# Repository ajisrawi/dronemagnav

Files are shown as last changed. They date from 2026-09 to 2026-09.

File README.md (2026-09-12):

# DroneMagNav — magnetic-anomaly navigation board for drones

GNSS-denied positioning from the Earth's crustal magnetic field, plus a
phone-operated great-circle route planner.

```
  LIS3MDL magnetometer ─┐                          ┌─ WDMAM anomaly map (SD)
  BMI088 IMU ───────────┼─ ESP32-S3 ─ particle ────┤  WMM core field model
  BMP280 baro ──────────┘   filter    matching     └─ Tolles-Lawson compensation
        │                        │
   u-blox GNSS (init/truth)      ├─ MAVLink GPS_INPUT → flight controller
                                 └─ WiFi AP → phone: offline map, route, upload
```

## Deliverables

| Item | Where | Status |
|---|---|---|
| Schematics (5 sheets) | `hardware/dronemagnav/*.kicad_sch`, `dronemagnav-schematic.pdf` | ERC 0 errors (1 intended warning) |
| PCB 64 × 60 mm, 4-layer, 30.5 mm Pixhawk hole pattern | `hardware/dronemagnav/dronemagnav.kicad_pcb` | routed, 0 unconnected, 0 electrical DRC |
| Fab package | `hardware/dronemagnav/fab/` (Gerber ZIP, drill, pick-and-place) | ready to upload |
| BOM | `docs/BOM.csv` | 28 line items, 56 parts, MPNs |
| Firmware (ESP32-S3, PlatformIO) | `firmware/`, images in `firmware/release/` | compiles with 0 warnings (Arduino-ESP32 3.3.11); WMM core-field model validated 100/100 against NOAA test vectors (0.001 nT) |
| Phone UI | `firmware/sdcard/www/index.html` | offline map, tap-to-route, upload |
| SD-card preparation | `tools/prepare_sd.py` | WDMAM v2 (1.5 GB text) → 51.9 MB binary grid, verified by `tools/wdmam_check.py`; WMM, coastline |
| Design document | `DroneMagNav-Design-Document.pdf` | study, diagrams, PCB, BOM, verification |

## Hardware
| Block | Part | Why |
|---|---|---|
| MCU / radio | ESP32-S3-WROOM-1-N16R8 | WiFi AP for the phone page, BLE, native USB, 8 MB PSRAM for map tiles + particle filter |
| Magnetometer | LIS3MDL (SPI) | 16-bit, ~40 nT after averaging; RM3100 upgrade via mast connector J5 |
| IMU | BMI088 (SPI) | drone-grade accel + gyro, vibration-robust |
| Barometer | BMP280 (SPI) | altitude for the field model |
| GNSS | u-blox MAX-M10S + U.FL | initialisation and truth reference |
| Storage | microSD (SDMMC 4-bit) | world anomaly map, WMM, coastline, web page |
| Interfaces | USB-C, JST-GH TELEM (MAVLink, 5 V in), JST-GH sensor mast (I2C) | Pixhawk-standard |
| Power | USB/FC 5 V → AMS1117-3.3 (digital) + AP2112K-3.3 (sensors) | separate clean sensor rail |

## How it navigates
1. **Compensate** the scalar field for the drone's own magnetism (18-term
   Tolles-Lawson, fitted once in flight with GNSS).
2. **Predict** position with the flight controller's velocity (or IMU dead
   reckoning) in a 600-particle filter.
3. **Update** each particle against *WMM core field + WDMAM anomaly* at the
   particle's location; resample; output mean and 1-σ.
4. **Feed** the estimate to the autopilot as `GPS_INPUT` when GNSS is lost.

**Expectations, honestly:** the WDMAM world grid is 3 arc-min (~5 km) and
upward-continued to 5 km, so with it alone you get drift-free
*kilometre-class* positioning — right for oceanic/jammed cruise, not landing.
Load a local aeromagnetic survey (`/maps/local.bin`, same format) for tens of
metres at drone altitude.

## Routing
The phone page shows an offline world coastline, you tap START and DEST, the
board computes the **great-circle** (shortest) path as evenly spaced waypoints
and uploads them to the flight controller as a MAVLink mission.

## Build / flash / prepare
See `firmware/README.md`. Short version: `pio run -t upload` over USB-C, then
`python tools/prepare_sd.py --wdmam <file> --wmm WMM.COF --coast <geojson>`
and copy `firmware/sdcard/*` to the card.

## Status / caveats
- Prototype; not certified for any regulated use.
- Firmware builds cleanly (PlatformIO, pioarduino platform, Arduino-ESP32
  core 3.3.11: 0 warnings, 1.08 MB flash of 4 MB app partition, 94 KB RAM).
  Ready-to-flash images are in `firmware/release/`. It has not yet run on
  real hardware, since the board has not been built.
- Vias in pads: 74 power vias were moved out of their pads into dog-bone
  stubs. Three remain where the routing leaves no room (BMI088 pads 2 and 4,
  microSD VDD pad) and must be filled and capped, see
  `hardware/dronemagnav/fab/FABRICATION-NOTES.md` (included in the Gerber ZIP).
- MAX-M10S straps checked against the u-blox integration manual
  (UBX-20053088 R05): `VIO_SEL` left open selects 3.3 V I/O, which is what the
  board supplies, so no change was needed. TIMEPULSE is tied inside the module
  to SAFEBOOT_N, so the firmware keeps GPIO16 input-only.
- Map data: WDMAM from the link you supplied; WMM.COF (NOAA) and Natural Earth
  coastline are free downloads you run through `prepare_sd.py`.

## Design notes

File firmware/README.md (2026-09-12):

# DroneMagNav firmware (ESP32-S3)

Magnetic-anomaly navigation (MagNav) + great-circle route planner for drones.

```
firmware/
├── platformio.ini          build config (PlatformIO, Arduino-ESP32, N16R8)
├── partitions.csv          16 MB flash layout (dual OTA app slots)
├── src/
│   ├── main.cpp            sensor loop, attitude, MagNav filter, FC feed
│   ├── pins.h              board pin map (schematic rev A)
│   ├── sensors/            bmi088.h  lis3mdl.h  bmp280.h  (register-level SPI)
│   ├── nav/
│   │   ├── wmm.h           World Magnetic Model core field (coeffs from SD)
│   │   ├── wdmam_map.h     anomaly-map window cache (WDMAM / local survey)
│   │   ├── tolles_lawson.h 18-term aircraft-field compensation + fit
│   │   ├── particle_filter.h  600-particle MagNav estimator
│   │   └── geo.h           great-circle distance / bearing / waypoints
│   └── comm/
│       ├── gnss.h          u-blox NMEA parser
│       ├── mavlink_lite.h  MAVLink v2: heartbeat, GPS_INPUT, mission upload
│       └── web_ui.h        WiFi AP + HTTP API for the phone page
└── sdcard/                 staging tree for the microSD (see tools/prepare_sd.py)
    ├── www/index.html      mobile map page (offline coastline, tap-to-route)
    └── maps/               wdmam.bin, WMM.COF, coast.json  (generated)
```

## 0. Ready-made images (no toolchain needed)
`release/` holds the verified build (Arduino-ESP32 core 3.3.11, 0 warnings,
1.08 MB flash / 94 KB RAM). One command with [esptool](https://pypi.org/project/esptool/):
```bash
esptool --chip esp32s3 --port COM5 --baud 921600 write-flash 0x0 release/dronemagnav-firmware.factory.bin
```
(`factory.bin` already contains bootloader, partition table and app.)

## 1. Install the toolchain
Install [PlatformIO Core](https://platformio.org/install/cli) (or the VS Code
extension), e.g. `pip install platformio`. `platformio.ini` points at the
pioarduino build of the Espressif platform, so the toolchain and Arduino-ESP32
core are fetched from GitHub on the first build (~1.5 GB, one time).

## 2. Build
```bash
cd firmware
pio run
```
Verified result: `[SUCCESS]`, RAM 29.3 % (95,876 B), Flash 25.7 % (1,077,723 B
of the 4 MB app partition), no compiler warnings.

## 3. Flash (USB-C, no external programmer)
```bash
pio run -t upload
```
First time only: hold **BOOT**, tap **RESET**, release BOOT — the ESP32-S3
enters its ROM bootloader on the native USB port. Afterwards the USB-CDC
auto-reset handles it. `pio device monitor -b 115200` shows the boot log.

## 4. Prepare the microSD card
```bash
python tools/prepare_sd.py --wdmam data/<WDMAM file> --wmm WMM.COF --coast ne_110m_coastline.geojson
```
then copy `firmware/sdcard/*` to the card root (FAT32, ≤ 32 GB recommended).

| File | Source |
|---|---|
| `maps/wdmam.bin` | converted from the WDMAM v2 text grid you supplied (1.5 GB xyz, 26 M lines → 7200 × 3601 int16 cells, 51.9 MB; ~2 min) |
| `maps/WMM.COF` | NOAA/NCEI World Magnetic Model coefficients (free) |
| `maps/coast.json` | Natural Earth 1:110m coastline GeoJSON (public domain) |
| `maps/local.bin` | optional: your own high-resolution aeromagnetic survey, same format |

## 5. Use it
1. Power from USB-C or the flight controller TELEM port. Join WiFi
   **DroneMagNav** / `magnav123`, open **http://192.168.4.1/** on your phone.
2. **Calibrate once** (Tolles-Lawson): with GNSS fix, tap *Start calibration*,
   fly pitch/roll/yaw manoeuvres on four headings for ~3 min, tap *Stop*.
   Coefficients are saved to `/cal/tl.bin`.
3. **Route:** tap *Set START = here* (or tap the map), tap the destination,
   *Compute route* → great-circle waypoints → *Upload to flight controller*.
4. **MagNav:** when GNSS is lost the filter takes over automatically (or tap
   *Init* to force it) and streams its fix to the FC as `GPS_INPUT`
   (ArduPilot: set `GPS_TYPE=14`, or `GPS_TYPE2=14` for blended use).

## Honest performance expectations
The WDMAM world grid is 3 arc-minutes (~5 km) and is upward-continued to
5 km altitude — it only contains long-wavelength anomalies. With it alone the
filter gives **kilometre-class** positioning, drift-free: good for oceanic /
GNSS-jammed cruise, not for precision landing. For tens-of-metres accuracy at
drone altitude load a local aeromagnetic survey as `/maps/local.bin`. The
LIS3MDL is adequate for the world grid; an RM3100 on the mast connector (J5)
is the upgrade for local-survey navigation.

Not compile-verified on hardware yet — see the project README for status.

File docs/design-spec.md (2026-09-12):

# DroneMagNav — Design Specification (rev A)

## 1. Purpose
A drone-mountable navigation module that estimates position without GNSS by
matching the measured total magnetic field against the World Digital Magnetic
Anomaly Map (WDMAM), fused with inertial dead reckoning; and a phone interface
to plan and upload direct (great-circle) routes.

## 2. Architecture
| Function | Implementation |
|---|---|
| Compute + radio | ESP32-S3-WROOM-1-N16R8: dual-core 240 MHz, 8 MB PSRAM, WiFi/BLE, USB-CDC |
| Sensing | LIS3MDL mag, BMI088 IMU, BMP280 baro — one SPI bus at 8–10 MHz |
| Reference | u-blox MAX-M10S GNSS on UART0 pads (GPIO43/44), PPS on GPIO16 |
| Map storage | microSD, SDMMC 4-bit (GPIO38–42, 47), card detect GPIO48 |
| Flight controller | UART2 (GPIO4/5) MAVLink v2, Pixhawk TELEM pinout on JST-GH J2 |
| External sensor | I2C1 (GPIO1/2) + interrupt GPIO3 on JST-GH J5 (mast-mounted RM3100) |
| Power | USB-C VBUS ⊕ FC 5 V (SS14 diode-OR) → AMS1117-3.3 → +3V3; AP2112K-3.3 → +3.3VA |

## 3. Pin map
| ESP32-S3 | Net | | ESP32-S3 | Net |
|---|---|---|---|---|
| IO12 | SPI_SCK | | IO38/39/40/41/42/47 | SD_CLK/CMD/D0/D1/D2/D3 |
| IO11 | SPI_MOSI | | IO48 | SD_DET |
| IO13 | SPI_MISO | | TXD0 (43) / RXD0 (44) | GNSS RXD / TXD |
| IO10 / IO9 | CS_ACC / CS_GYR | | IO16 | GNSS_PPS |
| IO14 / IO21 | CS_MAG / CS_BARO | | IO4 / IO5 | FC_RXD / FC_TXD |
| IO6 / IO7 / IO8 | INT_ACC / INT_GYR / MAG_DRDY | | IO1 / IO2 / IO3 | I2C_SDA / I2C_SCL / MAST_INT |
| IO35 / IO36 / IO37 | LED_NAV / LED_FIX / LED_LINK | | EN / IO0 | RESET / BOOT buttons |

## 4. Connectors
- **J1 USB-C** — power (VBUS) + native USB (D+/D− through USBLC6-2SC6 ESD).
- **J2 FC_TELEM (JST-GH 6)** — 1 VCC 5 V in, 2 FC TX → board, 3 board TX → FC, 4/5 NC, 6 GND.
- **J3 microSD** — Hirose DM3AT push-push.
- **J4 GNSS antenna** — U.FL, passive antenna, 50 Ω trace.
- **J5 SENSOR_MAST (JST-GH 6)** — 1 +3.3VA, 2 GND, 3 SDA, 4 SCL, 5 INT, 6 +5 V.

## 5. PCB
64 × 60 mm, 4 layers (F.Cu signals / In1 GND / In2 +3V3 / B.Cu signals),
30.5 mm M3 mounting pattern. ESP32 antenna at the top edge with a full copper
keep-out (module courtyard respected). USB-C left edge, microSD right edge,
GNSS + U.FL top-right, sensors centre, magnetometer bottom-centre away from
the regulators (bottom-left). Rules: 0.2 mm track, 0.15 mm clearance,
0.45/0.2 mm vias. Power vias are dog-boned outside their pads
(`tools/dogbone_vias.py`); three 0.4 mm vias stay inside pads where the
routing leaves no room (BMI088 pads 2/4, microSD VDD pad 4) and the
fabrication notes (`hardware/dronemagnav/fab/FABRICATION-NOTES.md`) require
those to be filled and capped.

## 6. Firmware
See `firmware/README.md` for the module map. Key algorithms:
- **WMM** degree-12 spherical-harmonic core field, coefficients from `WMM.COF`.
- **AnomalyMap** 96 × 96-cell PSRAM window over the int16 nT grid on SD; bilinear lookup.
- **TollesLawson** 18-term compensation; ridge-regularised least squares fit from a calibration flight.
- **MagNavPF** 600 particles (lat, lon, bias); systematic resampling at ESS < N/2, roughening.
- **MavlinkLite** HEARTBEAT, GPS_INPUT, MISSION_COUNT/ITEM_INT upload; parses GLOBAL_POSITION_INT / VFR_HUD.
- **WebUI** AP `DroneMagNav`, HTTP API: `/api/status`, `/api/route`, `/api/upload`, `/api/coast`, `/api/anom`, `/api/cal`, `/api/init`.

## 7. Map data pipeline
`tools/prepare_sd.py` converts the WDMAM grid (xyz/NetCDF/GeoTIFF) to
`/maps/wdmam.bin` (32-byte header + int16 nT, 3′ world grid ≈ 52 MB), and
stages `WMM.COF`, `coast.json` (Natural Earth 1:110m) and the web page.

The supplied WDMAM file is the v2 text distribution: 1.5 GB, 26 M lines of
`lon lat anomaly_nT source ...`, columns −179.95…180.00° and rows
90…−90° at 0.05°. The converter reads it in 2 M-line chunks, moves the
180.00° column to the front so the grid starts at exactly −180° (the
firmware wraps longitude modulo the grid width), and writes 7200 × 3601
cells. `tools/wdmam_check.py` re-reads sample lines from the source and
confirms the binary holds the same values at the cells the firmware addresses.

## 8. Verification
| Check | Result |
|---|---|
| Schematic ERC | 0 errors, 1 warning (BMI088 SDO1/SDO2 both on MISO — per Bosch reference design) |
| Netlist, 21 critical nets | 21/21 |
| PCB connectivity | 0 unconnected |
| PCB electrical DRC | 0 violations (22 silkscreen notes) |
| WMM evaluator vs NOAA WMM2025 test values | 100/100 points, worst error 0.001 nT (tools/wmm_check.py) |
| WDMAM SD grid vs source text file | 7200 × 3601 cells, 100 % valid, 225 sample cells identical (tools/wdmam_check.py) |
| MAX-M10S straps vs u-blox integration manual UBX-20053088 R05 | VIO_SEL open = 3.3 V I/O as built; V_BCKP on +3V3 within 1.5–3.6 V; RESET_N pull-up acceptable; TIMEPULSE–SAFEBOOT_N tie → GPIO16 input-only |
| Vias in pads after dog-bone pass (tools/fab_audit.py) | 74 moved out; 3 remain in small pads (fill & cap), 2 in thermal pads; DRC 0 unconnected, 0 electrical |
| Firmware build (PlatformIO, pioarduino espressif32 55.3.311, Arduino-ESP32 3.3.11) | SUCCESS, 0 warnings; flash 1,077,723 B (25.7 % of app partition), RAM 95,876 B (29.3 %) |

## 9. Known limitations
- WDMAM resolution/altitude → km-class accuracy without a local survey.
- LIS3MDL noise adequate for the world grid only; RM3100 recommended for local surveys.
- Magnetic interference from ESCs/motors must be handled by mounting distance and the Tolles-Lawson calibration.
- Firmware compiles (0 warnings) but has not yet run on hardware; the
  calibration flight and MagNav-vs-GNSS benchmark remain to be done.
- V_BCKP is tied to +3V3 (in range, but no hot start after a power cycle);
  fit a backup cell on V_BCKP if that matters.

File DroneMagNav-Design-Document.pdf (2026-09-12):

DESIGN DOCUMENT · REV A

# DroneMagNav

## Magnetic-anomaly navigation board and route planner for drones

ESP32-S3 · BMI088 IMU · LIS3MDL magnetometer · BMP280 · u-blox MAX-M10S WDMAM world anomaly map on microSD · particle-filter MagNav · MAVLink to the autopilot Phone web app: offline world map, tap start/destination, great-circle route upload

Project | DroneMagNav (GNSS-denied drone navigation)
Revision | A - schematic + routed PCB + firmware release
Date | 12 September 2026
Prepared by | eng.ahmad@gmail.com · generated with KiCad 10
Design status | ERC clean · netlist verified · PCB routed, 0 electrical DRC
Classification | Prototype / experimental - not certified

Appendix A contains the full KiCad schematic set (5 sheets, A3).

DroneMagNav - Design Document | Rev A · 12 Sep 2026

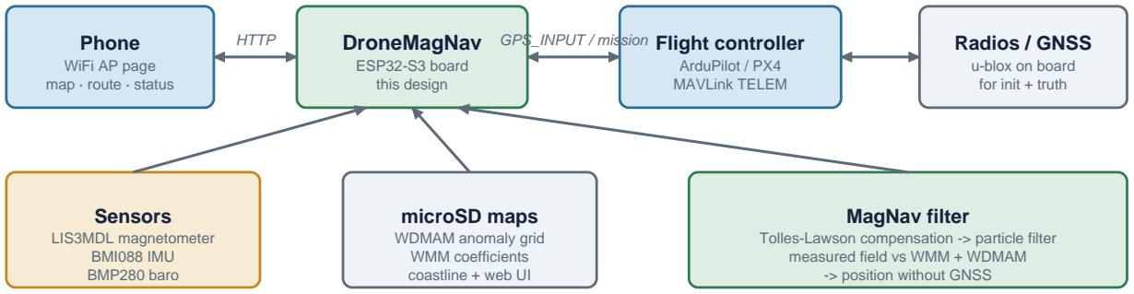
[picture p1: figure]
Phone WiFi AP page map · route · status; DroneMagNav; ESP32-S3 board this design; Flight controller ArduPilot / PX4 MAVLink TELEM; Radios / GNSS u-blox on board for init + truth; HTTP; GPS_INPUT / mission; Sensors LIS3MDL magnetometer BMI088 IMU BMP280 baro; microSD maps WDMAM anomaly grid WMM coefficients coastline + web UI; MagNav filter Tolles-Lawson compensation -> particle filter measured field vs WMM + WDMAM -> position without GNSS

Prototype - not certified for any regulated use | Page 2

# 1 Executive summary

DroneMagNav is a 64 x 60 mm navigation module for drones that estimates position without GNSS by matching the measured total magnetic field against the World Digital Magnetic Anomaly Map (WDMAM), fused with inertial dead reckoning in a particle filter. A u-blox GNSS receiver on the board initialises the filter and provides a truth reference; when GNSS is lost the MagNav estimate is streamed to the flight controller as a MAVLink GPS_INPUT source. A phone connects to the board's WiFi access point, shows an offline world map, and lets the operator tap a start and a destination; the board computes the shortest (great-circle) route and uploads it to the autopilot as a mission.
This release contains the complete KiCad schematic set, a routed four-layer PCB with manufacturing outputs, a bill of materials with part numbers, the ESP32-S3 firmware with the navigation algorithms and web interface, and the tools that convert the WDMAM data for the microSD card.

# 2 System architecture

Signal path: sensors -> compensation -> particle filter against the magnetic map -> position -> autopilot; route planned on the phone.

Figure 1 - System context

The Earth's crustal magnetic anomalies form a fixed, GNSS-independent map. Subtracting the smooth core field (World Magnetic Model) from the compensated scalar measurement leaves the anomaly, which the particle filter compares with the WDMAM grid at every particle's position. The filter is drift-free but its resolution is bounded by the map: the 3-arc-minute WDMAM grid (upward-continued to 5 km) gives kilometre-class positioning; a local aeromagnetic survey loaded in the same format brings that to tens of metres at drone altitude.

# 3 Hardware design

DroneMagNav PCB 64 x 60 mm, 4 layers

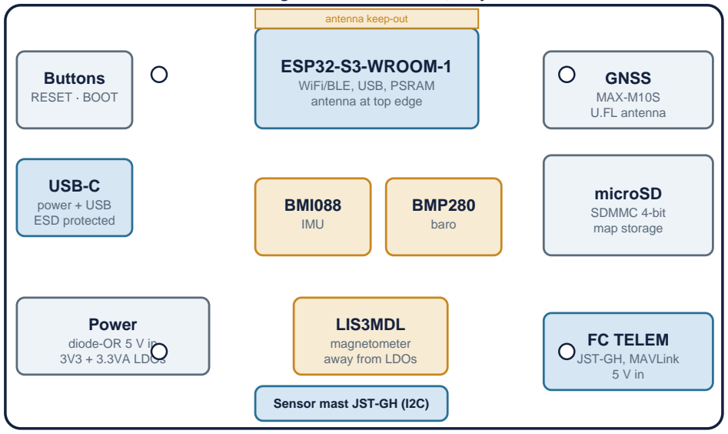
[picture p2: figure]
ESP32-S3-WROOM-1; WiFi/BLE, USB, PSRAM antenna at top edge; antenna keep-out; Buttons RESET · BOOT; USB-C power + USB ESD protected; GNSS MAX-M10S U.FL antenna; microSD SDMMC 4-bit map storage; BMI088 IMU; BMP280 baro; LIS3MDL magnetometer away from LDOs; Power diode-OR 5 V in 3V3 + 3.3VA LDOs; FC TELEM JST-GH, MAVLink 5 V in; Sensor mast JST-GH (I2C)

M3 holes on the 30.5 mm Pixhawk pattern
Figure 2 - Board floorplan
Block | Part | Notes
MCU / radio | ESP32-S3-WROOM-1-N16R8 | 16 MB flash, 8 MB PSRAM, WiFi/BLE, native USB; UART0 pads carry the GNSS
Magnetometer | LIS3MDL | 16-bit, +-4 gauss, ~40 nT after averaging; SPI
IMU | BMI088 | accel + gyro, drone grade; SPI, dual chip-select
Barometer | BMP280 | altitude input to the field model; SPI
GNSS | u-blox MAX-M10S + U.FL | init and truth; PPS to GPIO16
Storage | microSD (Hirose DM3AT) | SDMMC 4-bit, card detect
Interfaces | USB-C, JST-GH TELEM, JST-GH mast | USBLC6 ESD; Pixhawk TELEM pinout; I2C mast for RM3100
Power | SS14 diode-OR, AMS1117-3.3, AP2112K-3.3 | digital 3V3 and low-noise 3.3VA sensor rail

### 3.1 Magnetic cleanliness

The magnetometer sits at the bottom centre, 14 mm from the regulators and away from the USB and SD connectors; the ESP32 antenna keep-out is respected in full. The dominant interference on a drone is the motors and ESC currents, which no board layout can remove: the firmware's Tolles-Lawson calibration models it, and the sensor-mast connector J5 allows an external RM3100 on a boom for survey-grade use.

# 4 Navigation algorithms

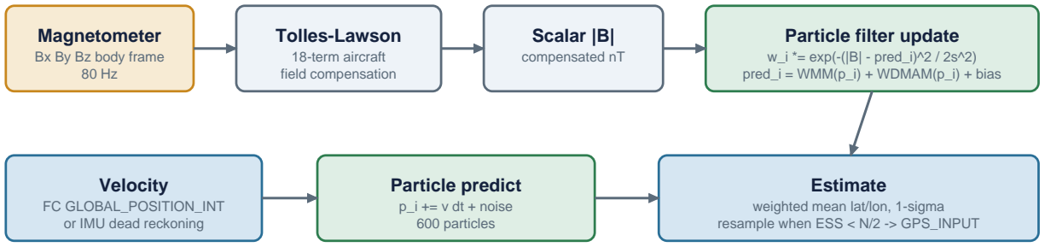
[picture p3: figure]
Magnetometer Bx By Bz body frame 80 Hz; Tolles-Lawson 18-term aircraft field compensation; Scalar |B| compensated nT; Particle filter update w_i *= exp(-(|B| - pred_i)^2 / 2s^2) pred_i = WMM(p_i) + WDMAM(p_i) + bias; Velocity FC GLOBAL_POSITION_INT or IMU dead reckoning; Particle predict p_i += v dt + noise 600 particles; Estimate weighted mean lat/lon, 1-sigma resample when ESS < N/2 -> GPS_INPUT

Figure 3 - MagNav particle filter dataflow

- WMM core field: degree-12 spherical-harmonic model evaluated per particle; coefficients read from the NOAA WMM.COF file on the card.
- WDMAM map window: 96 x 96 cells of the int16 nT world grid cached in PSRAM around the estimate, bilinear interpolation, seamless longitude wrap.
- Tolles-Lawson: 18 terms (permanent, induced, eddy) fitted by ridge-regularised least squares from a 3-minute calibration manoeuvre with GNSS; stored on the card.
- Particle filter: 600 particles (lat, lon, scalar bias); velocity from the flight controller or IMU; Gaussian likelihood with 40 nT sigma; systematic resampling with roughening.
- Routing: haversine distance, initial bearing, great-circle intermediate points at the chosen spacing; uploaded as NAV_TAKEOFF + NAV_WAYPOINT items.

# 5 PCB implementation

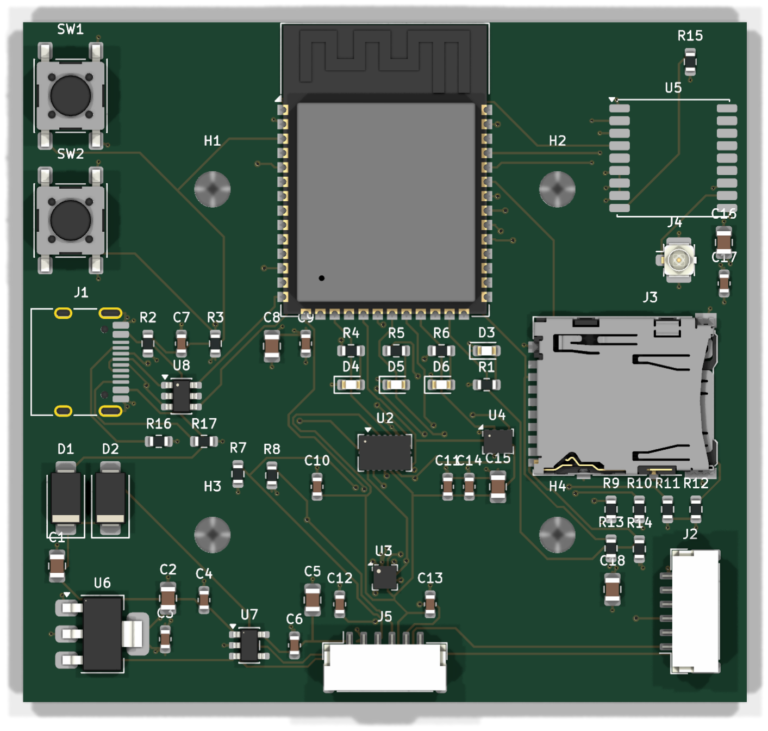
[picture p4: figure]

Figure 4 - Routed board, top side

Four layers: signals on the outer layers, solid GND (In1) and +3V3 (In2) planes inside, both notched under the module antenna. Autorouted with Freerouting constrained to the outer layers and the keep-outs, then scripted power fanout to the planes and hand-verified routes for the GNSS UART and the I2C bus. Rules: 0.2 mm track, 0.15 mm clearance, 0.45/0.2 mm vias. Power vias are dog-boned outside their pads (74 moved by tools/dogbone_vias.py); only three 0.4 mm vias remain in pads where the 0.5 mm-pitch BMI088 escapes and the microSD routing leave no room (U2 pads 2/4, J3 pad 4) and the fabrication notes require them to be filled and capped. Fab outputs: Gerbers, Excellon drill + map, pick-and-place, FABRICATION-NOTES.md, Gerber ZIP.

# 6 Bill of materials

References | Qty | Value | Manufacturer P/N
C1, C2, C5, C8, C15, C16, C18 | 7 | 10uF | CL21 series
C3, C6, C9, C10, C11, C12, ... | 9 | 100nF | CL10 series
C4, C7 | 2 | 1uF | CL10 series
D1, D2 | 2 | SS14 | SS14
D3 | 1 | PWR | 19-217/GHC-YR1S2/3T
D4 | 1 | NAV | 19-217/GHC-YR1S2/3T
D5 | 1 | FIX | 19-217/BHC-ZL1M2RY/3T
D6 | 1 | LINK | 19-217/Y2C-CQ2R2L/3T
J1 | 1 | USB-C | TYPE-C-31-M-12

References | Qty | Value | Manufacturer P/N
J2 | 1 | FC_TELEM | SM06B-GHS-TB
J3 | 1 | microSD | DM3AT-SF-PEJM5
J4 | 1 | GNSS_ANT | U.FL-R-SMT-1(10)
J5 | 1 | SENSOR_MAST | SM06B-GHS-TB
R1 | 1 | 1K | RC0603FR-071KL
R2, R3, R9, R10, R11, R12, ... | 9 | 10K | RC0603FR-0710KL
R4, R5, R6 | 3 | 330R | RC0603FR-07330RL
R7, R8 | 2 | 4.7K | RC0603FR-074.7KL
R16, R17 | 2 | 5.1K | RC0603FR-075.1KL
SW1 | 1 | RESET | PTS645SM43SMTR92
SW2 | 1 | BOOT | PTS645SM43SMTR92
U1 | 1 | ESP32-S3-WROOM -1-N16R8 | ESP32-S3-WROOM-1-N16R8
U2 | 1 | BMI088 | BMI088
U3 | 1 | LIS3MDL | LIS3MDLTR
U4 | 1 | BMP280 | BMP280
U5 | 1 | MAX-M10S | MAX-M10S-00B
U6 | 1 | AMS1117-3.3 | AMS1117-3.3
U7 | 1 | AP2112K-3.3 | AP2112K-3.3TRG1
U8 | 1 | USBLC6-2SC6 | USBLC6-2SC6

# 7 Firmware and phone interface

PlatformIO / Arduino-ESP32 project (firmware/): register-level SPI drivers for the three sensors, NMEA parser for the GNSS, a minimal MAVLink v2 stack (heartbeat, GPS_INPUT, mission upload, position/velocity intake), the navigation modules above, and a WiFi access point serving the phone page from the card. Flashing is over USB-C (native USB bootloader, no programmer). The phone page draws the Natural Earth coastline offline, pans/zooms by touch, places START/DEST by tap, shows the great-circle line, distance and bearing, and uploads the mission.

HTTP endpoint | Purpose
GET /api/status | mode, position, sigma, field, anomaly, heading, link states
GET /api/route?lat1&lon1;&lat2;&lon2;&alt;&s pacing; | great-circle waypoints, distance, bearing
POST /api/upload | send the last route to the flight controller as a mission
GET /api/anom?lat&lon;&span;&n; | anomaly grid for the heat overlay
POST /api/cal?start=1|0 | Tolles-Lawson calibration start/stop
POST /api/init?lat&lon; | force MagNav mode from a known position

# 8 Verification

Check | Tool | Result
Electrical rule check (5 sheets) | kicad-cli sch erc | 0 errors, 1 warning (BMI088 SDO1/SDO2 on MISO, per Bosch)
Netlist connectivity, 21 critical nets | tools/check_netlist.py | 21 / 21 pass
PCB connectivity | kicad-cli pcb drc | 0 unconnected pads
PCB electrical rules | kicad-cli pcb drc | 0 violations (22 silkscreen notes)
WMM core-field evaluator vs NOAA WMM2025 test values | tools/wmm_check.py | 100 / 100 points, worst error 0.001 nT
WDMAM SD-card grid vs source file (7200 x 3601 cells, 51.9 MB) | tools/wdmam_check.py | 225 sample cells identical, 100 % coverage
MAX-M10S straps vs u-blox integration manual UBX-20053088 R05 | manual, table 1 / sec. 4.1 | VIO_SEL open = 3.3 V I/O (as built); TIMEPULSE-SAFEBOOT_N tie honoured in firmware
Vias in pads after dog-bone pass | tools/fab_audit.py | 3 in small pads (listed for fill & cap), 2 in thermal pads, 0 unconnected, 0 DRC
Firmware build (PlatformIO, Arduino-ESP32 3.3.11) | pio run | SUCCESS, 0 warnings; flash 1.08 MB (25.7 %), RAM 94 KB (29.3 %); images in firmware/release

# 9 Limitations and next steps

- WDMAM resolution and 5 km altitude limit stand-alone accuracy to kilometre class; add a local survey map for metres.
- LIS3MDL is adequate for the world grid; use an RM3100 on the mast connector for survey-grade work.
- Order the board with filled-and-capped vias (three vias-in-pad, see FABRICATION-NOTES.md in the Gerber ZIP).

- Flash firmware/release/dronemagnav-firmware.factory.bin, run the calibration flight, benchmark MagNav against GNSS before relying on it.

# Appendix A - Schematic sheets

Root, power, MCU, sensors, GNSS + storage, interfaces - as plotted from KiCad. Every pin carries a drawn wire stub with its net label; the netlist is the authoritative artifact validated in Section 8.

1 | 2 | 3 | 4 | 5 | 6 | 7 | 8

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
F Date:
KiCad E.D.A. 10.0.3
Size: A3 | Rev: A Id: 1/6

Title: DroneMagNav - magnetic anomaly navigation board for drones

File: dronemagnav.kicad_sch

Sheet: /

DroneMagNav Project

ESP32-S3 + BMI088 + LIS3MDL + BMP280 + MAX-M10S + microSD

MCU

File: mcu.kicad_sch | Sensors File: sensors.kicad_sch | GNSS (u-blox MAX-M10S) and microSD map storage

File: gnss_storage.kicad_sch

Interfaces File: interfaces.kicad_sch Power File: power.kicad_sch

MagNav: measure Earth's crustal magnetic anomaly with the magnetometer, subtract the core field (WMM), match against the WDMAM map on the SD card

with a particle filter fused with IMU dead-reckoning -> GNSS-denied position. GNSS module gives initialisation and truth for testing.

Phone UI over WiFi AP: pick start/destination on the offline map, great-circle route + waypoints sent to the flight controller (MAVLink).

Prototype hardware - not certified for any regulated use.

### 10uF +5V GND

### SS14 D1

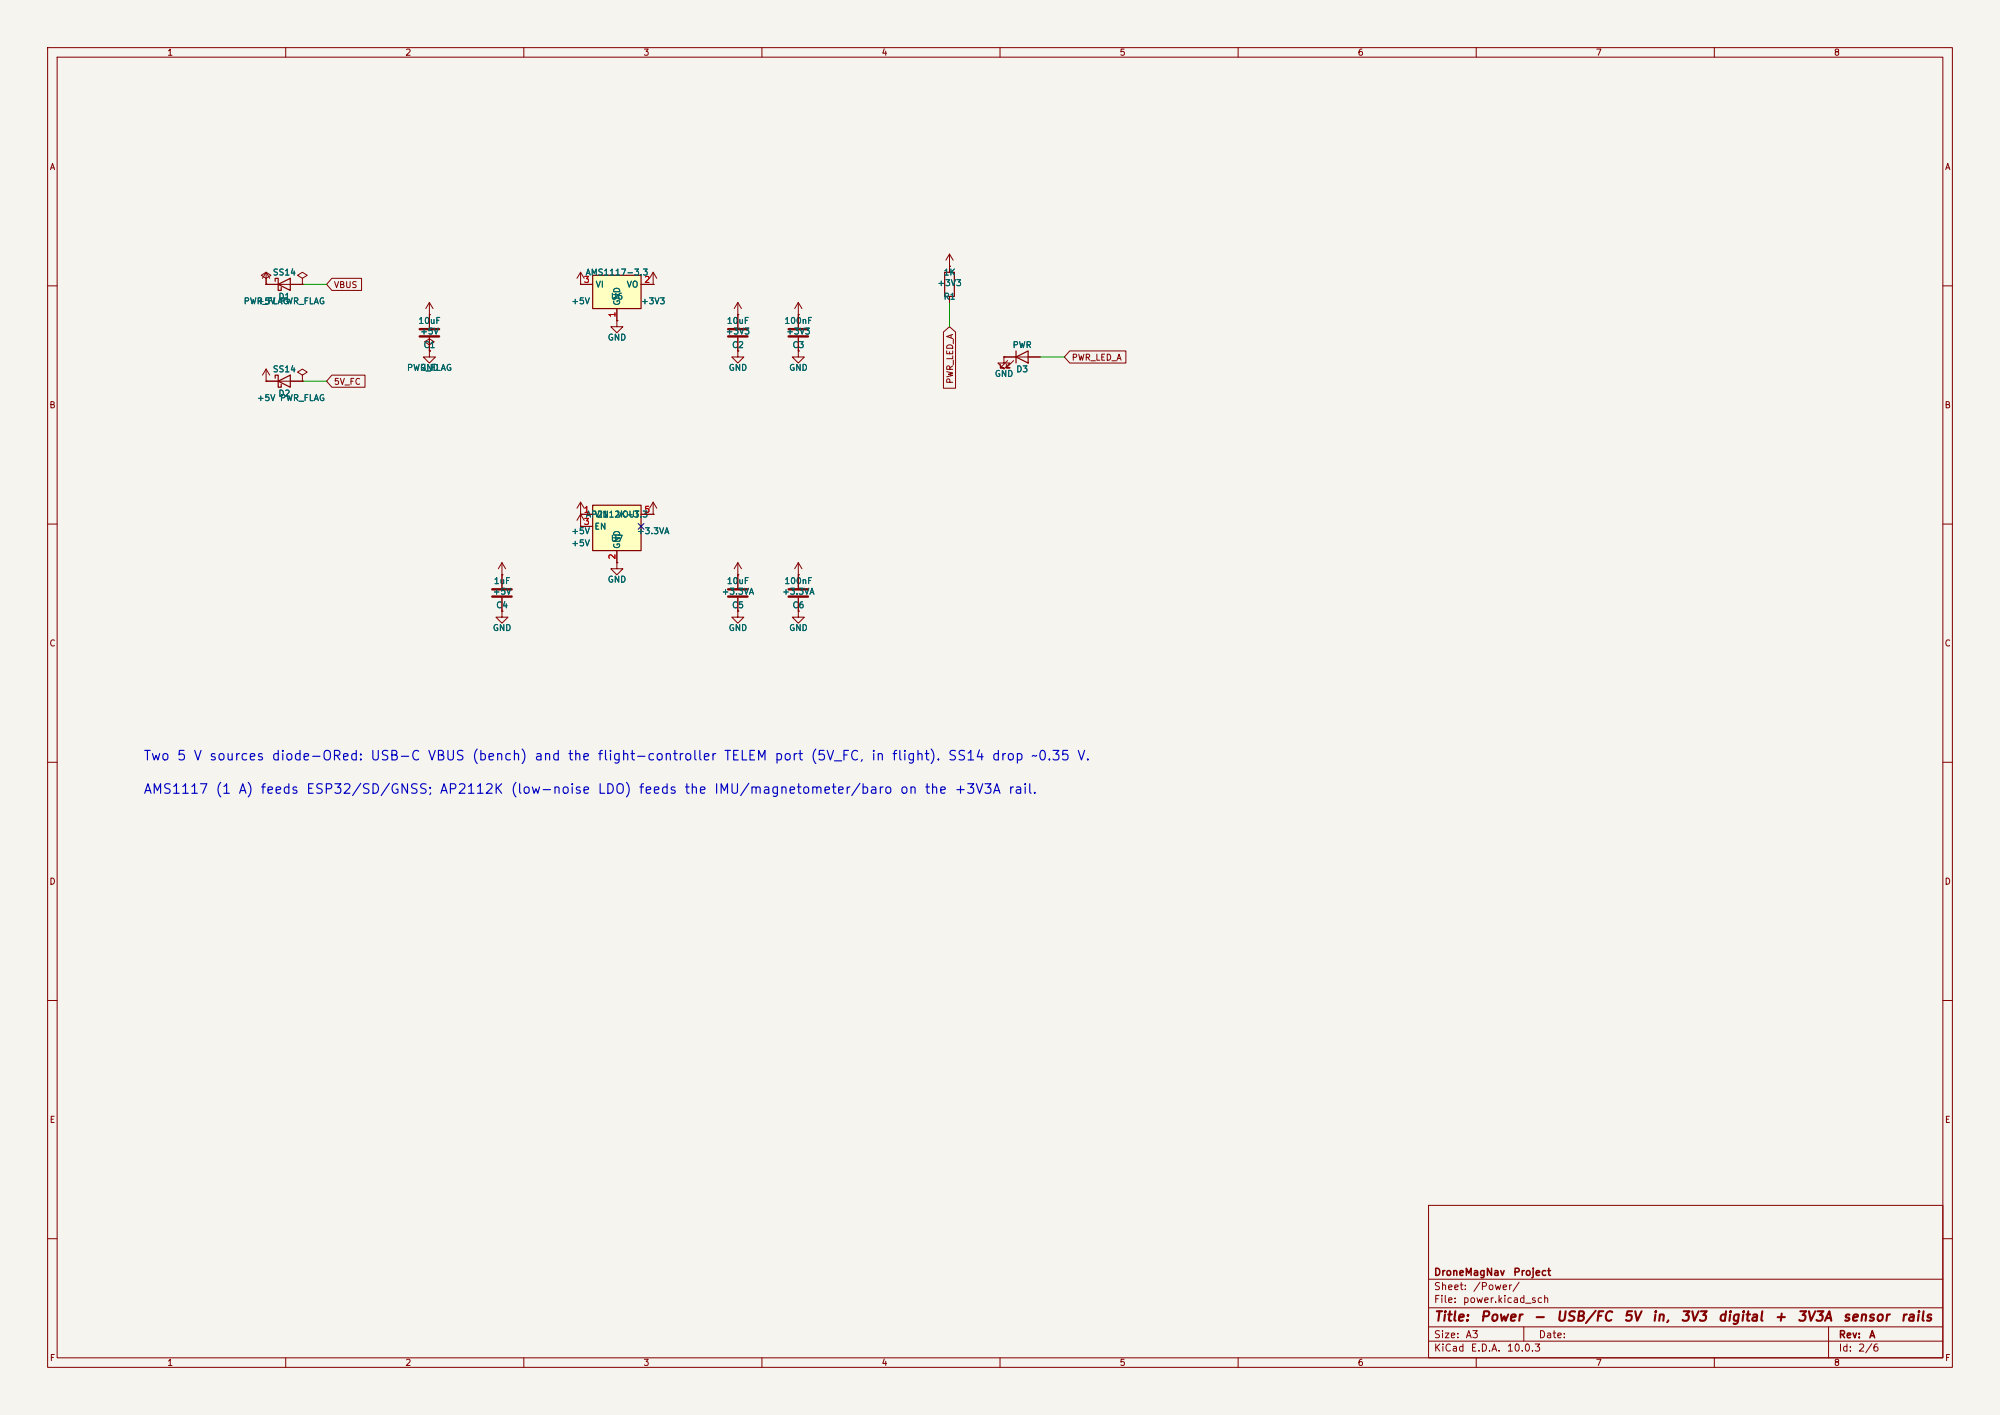
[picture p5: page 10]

VBUS AMS1117 (1 A) feeds ESP32/SD/GNSS; AP2112K (low-noise LDO) feeds the IMU/magnetometer/baro on the +3V3A rail.

Two 5 V sources diode-ORed: USB-C VBUS (bench) and the flight-controller TELEM port (5V_FC, in flight). SS14 drop ~0.35 V.

DroneMagNav Project
Sheet: /Power/
File: power.kicad_sch
Title: Power - USB/FC 5V in, 3V3 digital + 3V3A sensor rails

# 100nF +3V3 GND

# GND SW1 RESET R2

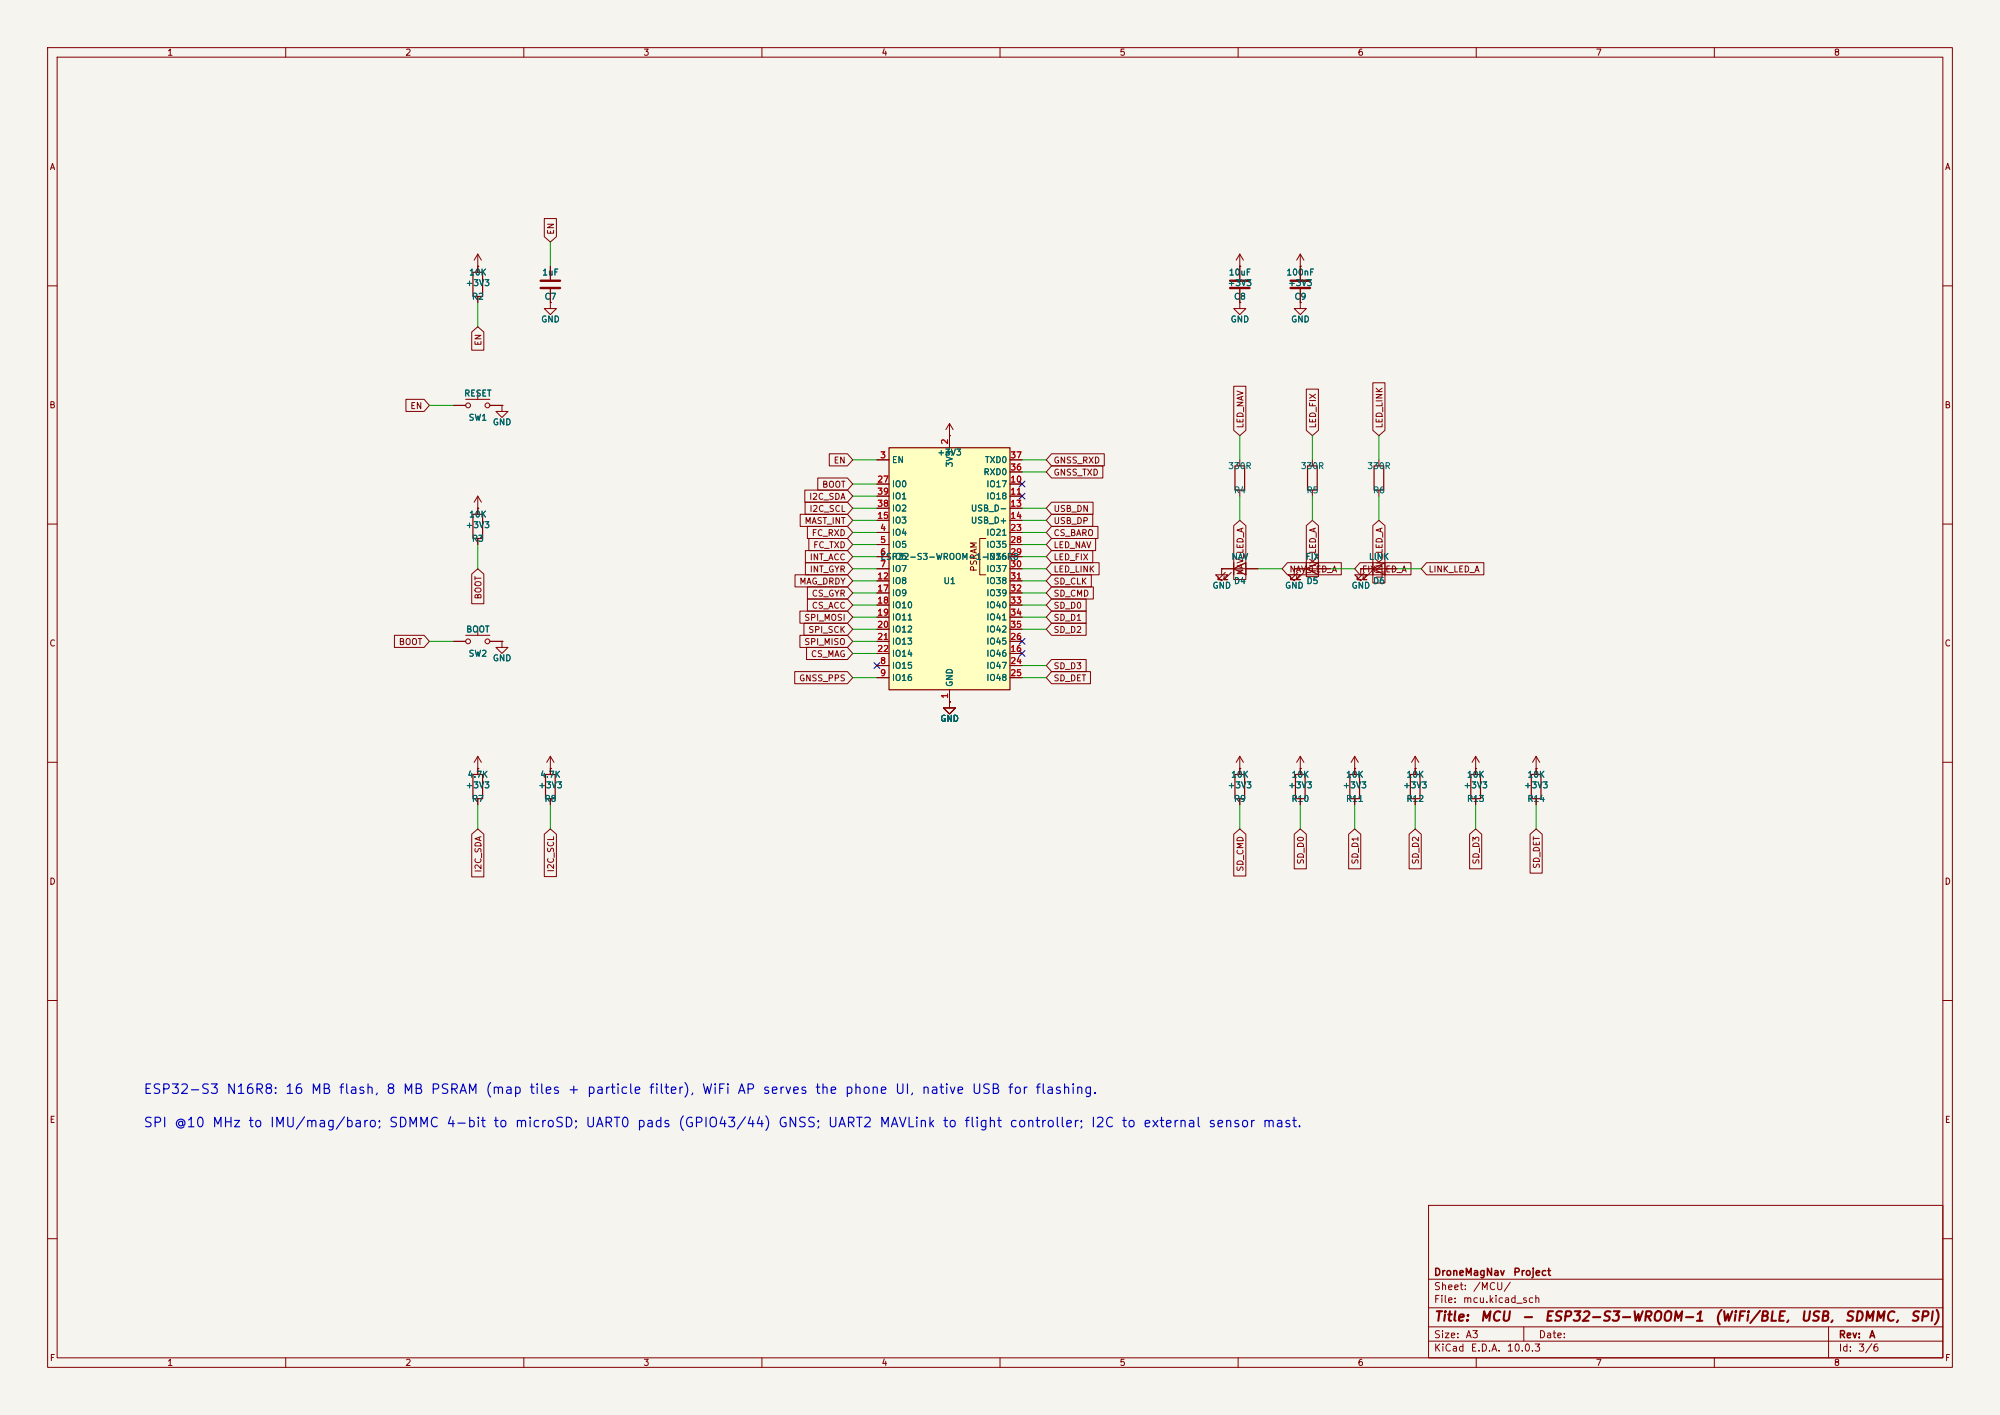
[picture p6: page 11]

DroneMagNav Project PSRAM GND

ESP32-S3 N16R8: 16 MB flash, 8 MB PSRAM (map tiles + particle filter), WiFi AP serves the phone UI, native USB for flashing.

Sheet: /MCU/
File: mcu.kicad_sch
Title: MCU - ESP32-S3-WROOM-1 (WiFi/BLE, USB, SDMMC, SPI)

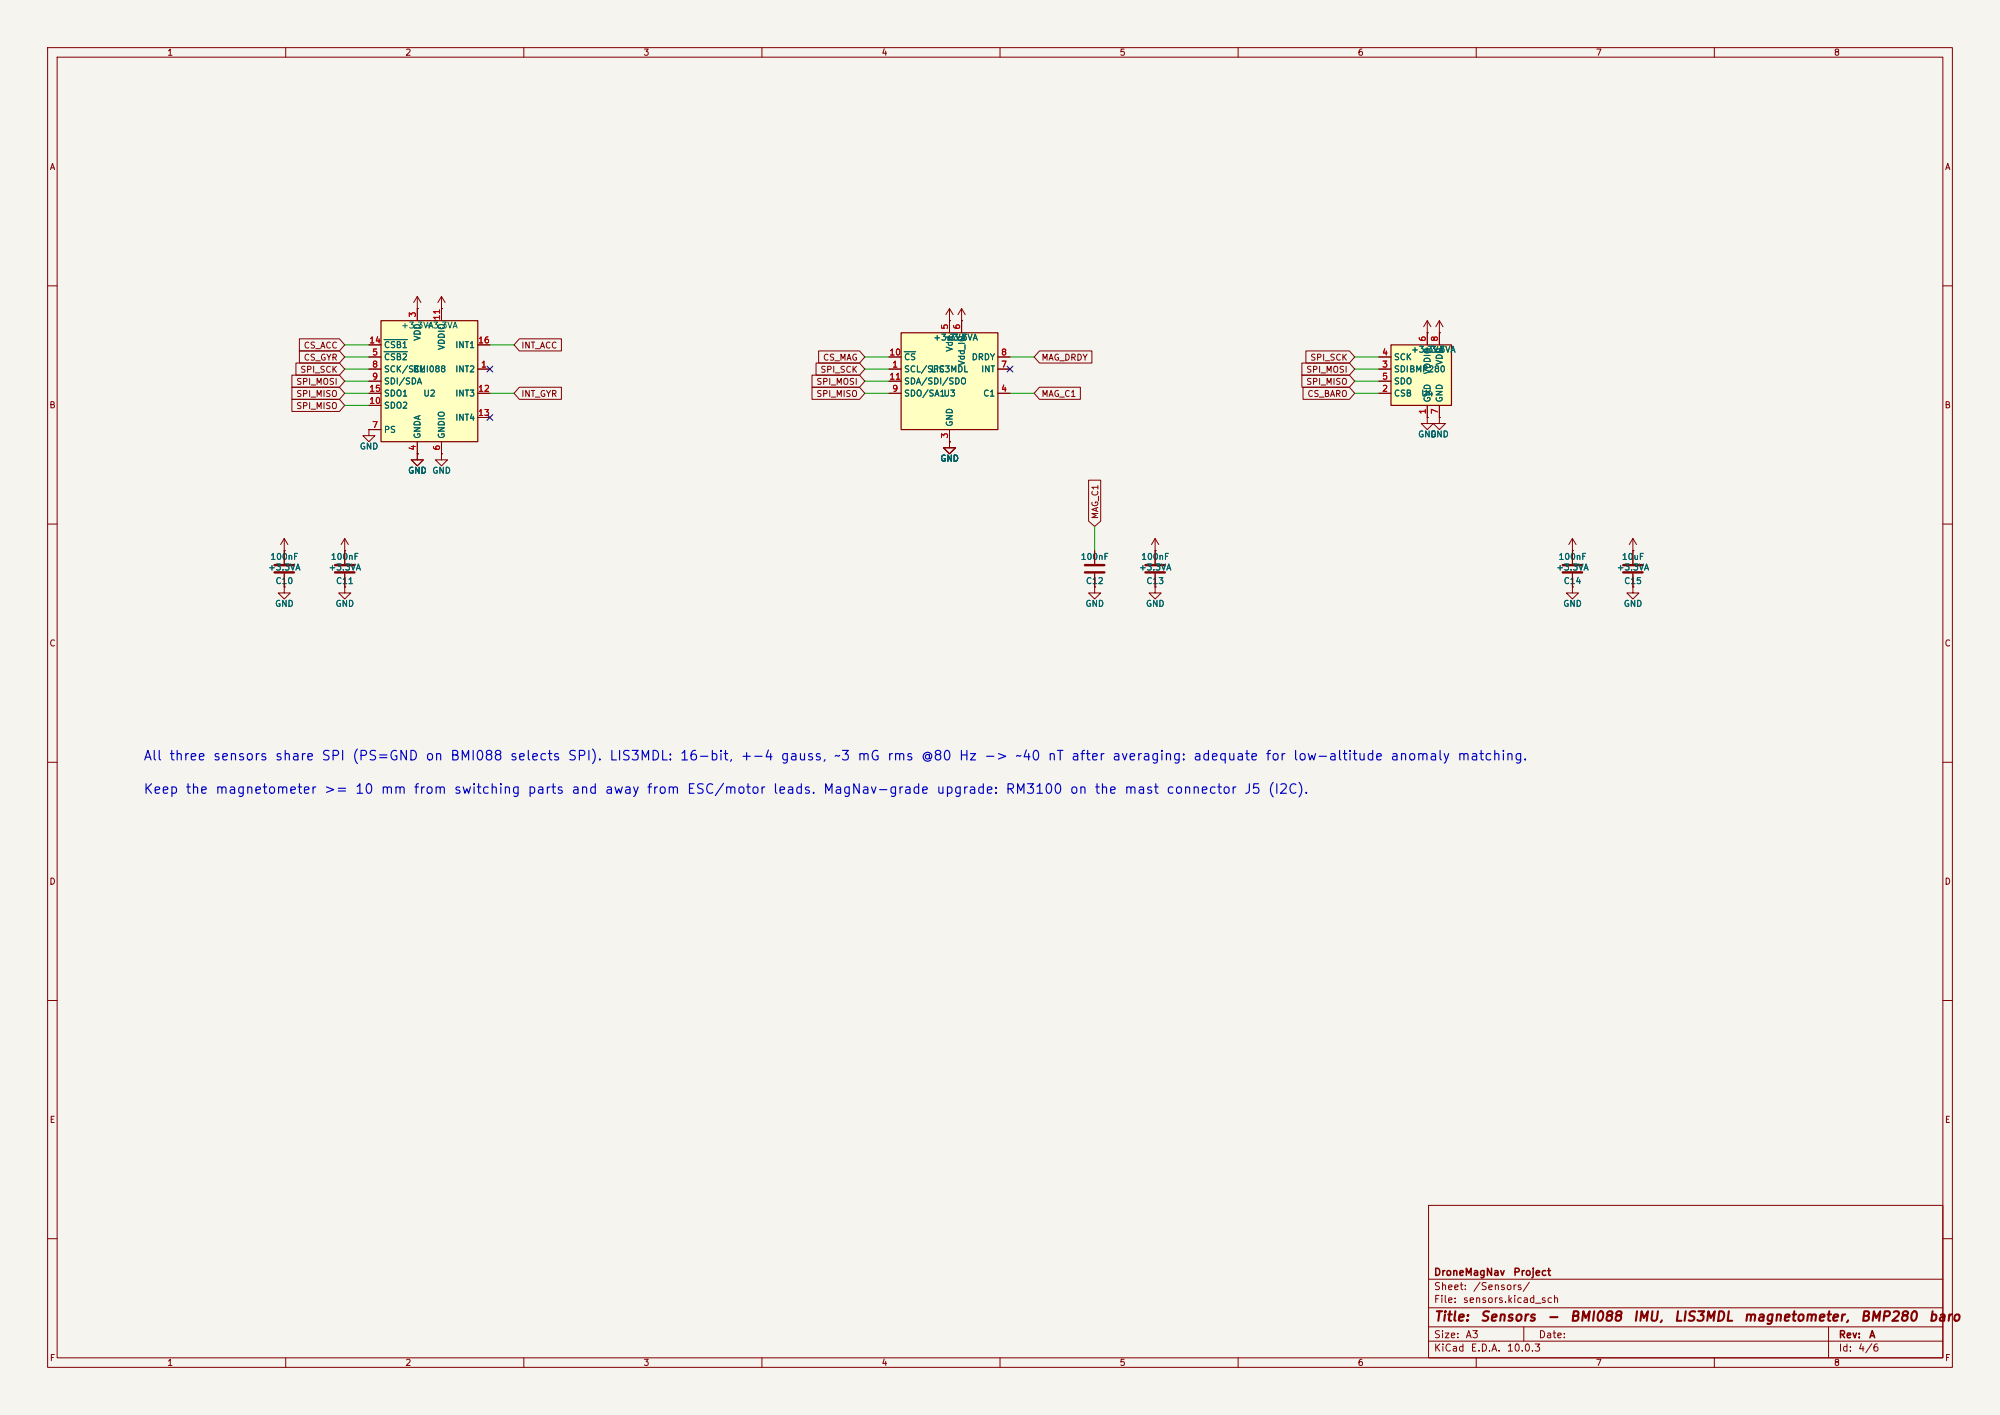
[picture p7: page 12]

All three sensors share SPI (PS=GND on BMI088 selects SPI). LIS3MDL: 16-bit, +-4 gauss, ~3 mG rms @80 Hz -> ~40 nT after averaging: adequate for low-altitude anomaly matching. GND +3.3VA GND U4 BMP280 GND
SPI_MOSI Keep the magnetometer >= 10 mm from switching parts and away from ESC/motor leads. MagNav-grade upgrade: RM3100 on the mast connector J5 (I2C).

Sheet: /Sensors/
File: sensors.kicad_sch
Title: Sensors - BMI088 IMU, LIS3MDL magnetometer, BMP280 baro

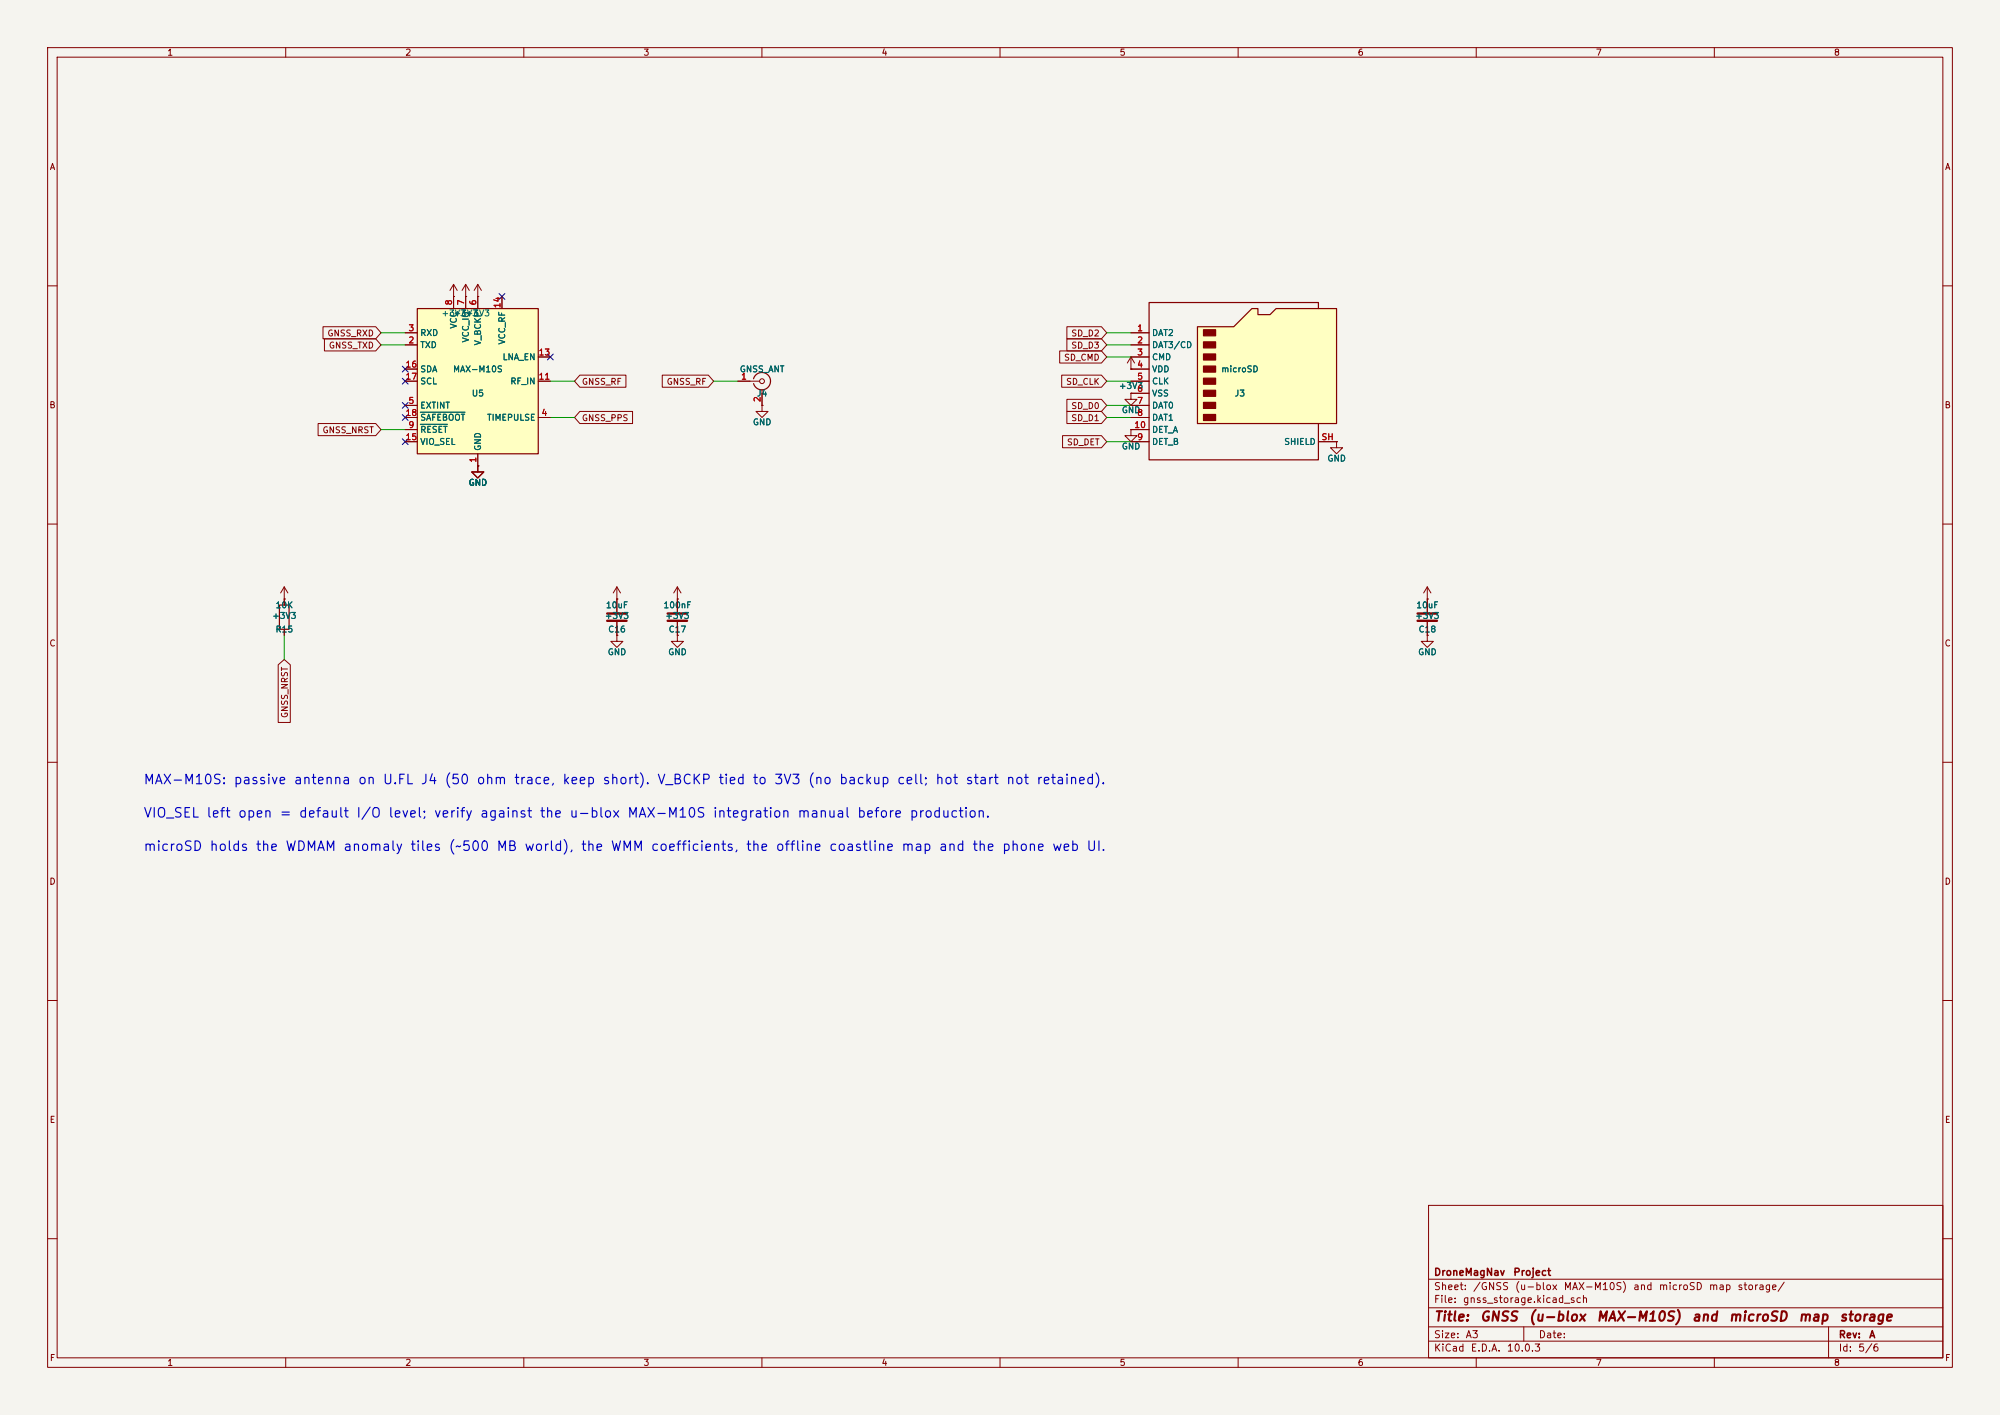
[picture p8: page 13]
GND; GND +3V3; 100nF GND +3V3 C16; 10uF +3V3+3V3GND; TXD 2 RXD 3; TIMEPULSE 4; EXTINT 5; V_BCKP; 6 VCC_IO; 7 VCC; 8 RESET 9 RF_IN 11; LNA_EN 13 VCC_RF 14; VIO_SEL 15; SDA 16 SCL 17; SAFEBOOT 18; U5 MAX-M10S; J4 GNSS_ANT GND; DAT2 1; DAT3/CD 2; CMD 3; VDD 4; CLK 5; VSS 6; DAT0 7; DAT1 8; DET_B 9; DET_A 10; SHIELD; J3 microSD; +3V3 GND; 10uF GND; GNSS_RF; SD_CLK; GNSS_NRST GNSS_TXD; GNSS_RXD; GNSS_PPS GNSS_NRST; SD_D2 SD_D3 SD_CMD; GND +3V3 R15; J4 GNSS_ANT 1; 100nF +3V3 GND

MAX-M10S: passive antenna on U.FL J4 (50 ohm trace, keep short). V_BCKP tied to 3V3 (no backup cell; hot start not retained). ⁺³V3+3V3 U5 MAX-M10S GND

SD_DET GNSS_RF microSD holds the WDMAM anomaly tiles (~500 MB world), the WMM coefficients, the offline coastline map and the phone web UI.

VIO_SEL left open = default I/O level; verify against the u-blox MAX-M10S integration manual before production.

DroneMagNav Project
Sheet: /GNSS (u-blox MAX-M10S) and microSD map storage/
File: gnss_storage.kicad_sch
Title: GNSS (u-blox MAX-M10S) and microSD map storage

VBUS | A4 CC1 | A5 D+ | A6 D- | A7
SBU1 | | | | A8 CC2 B5 D+ B6 D- B7

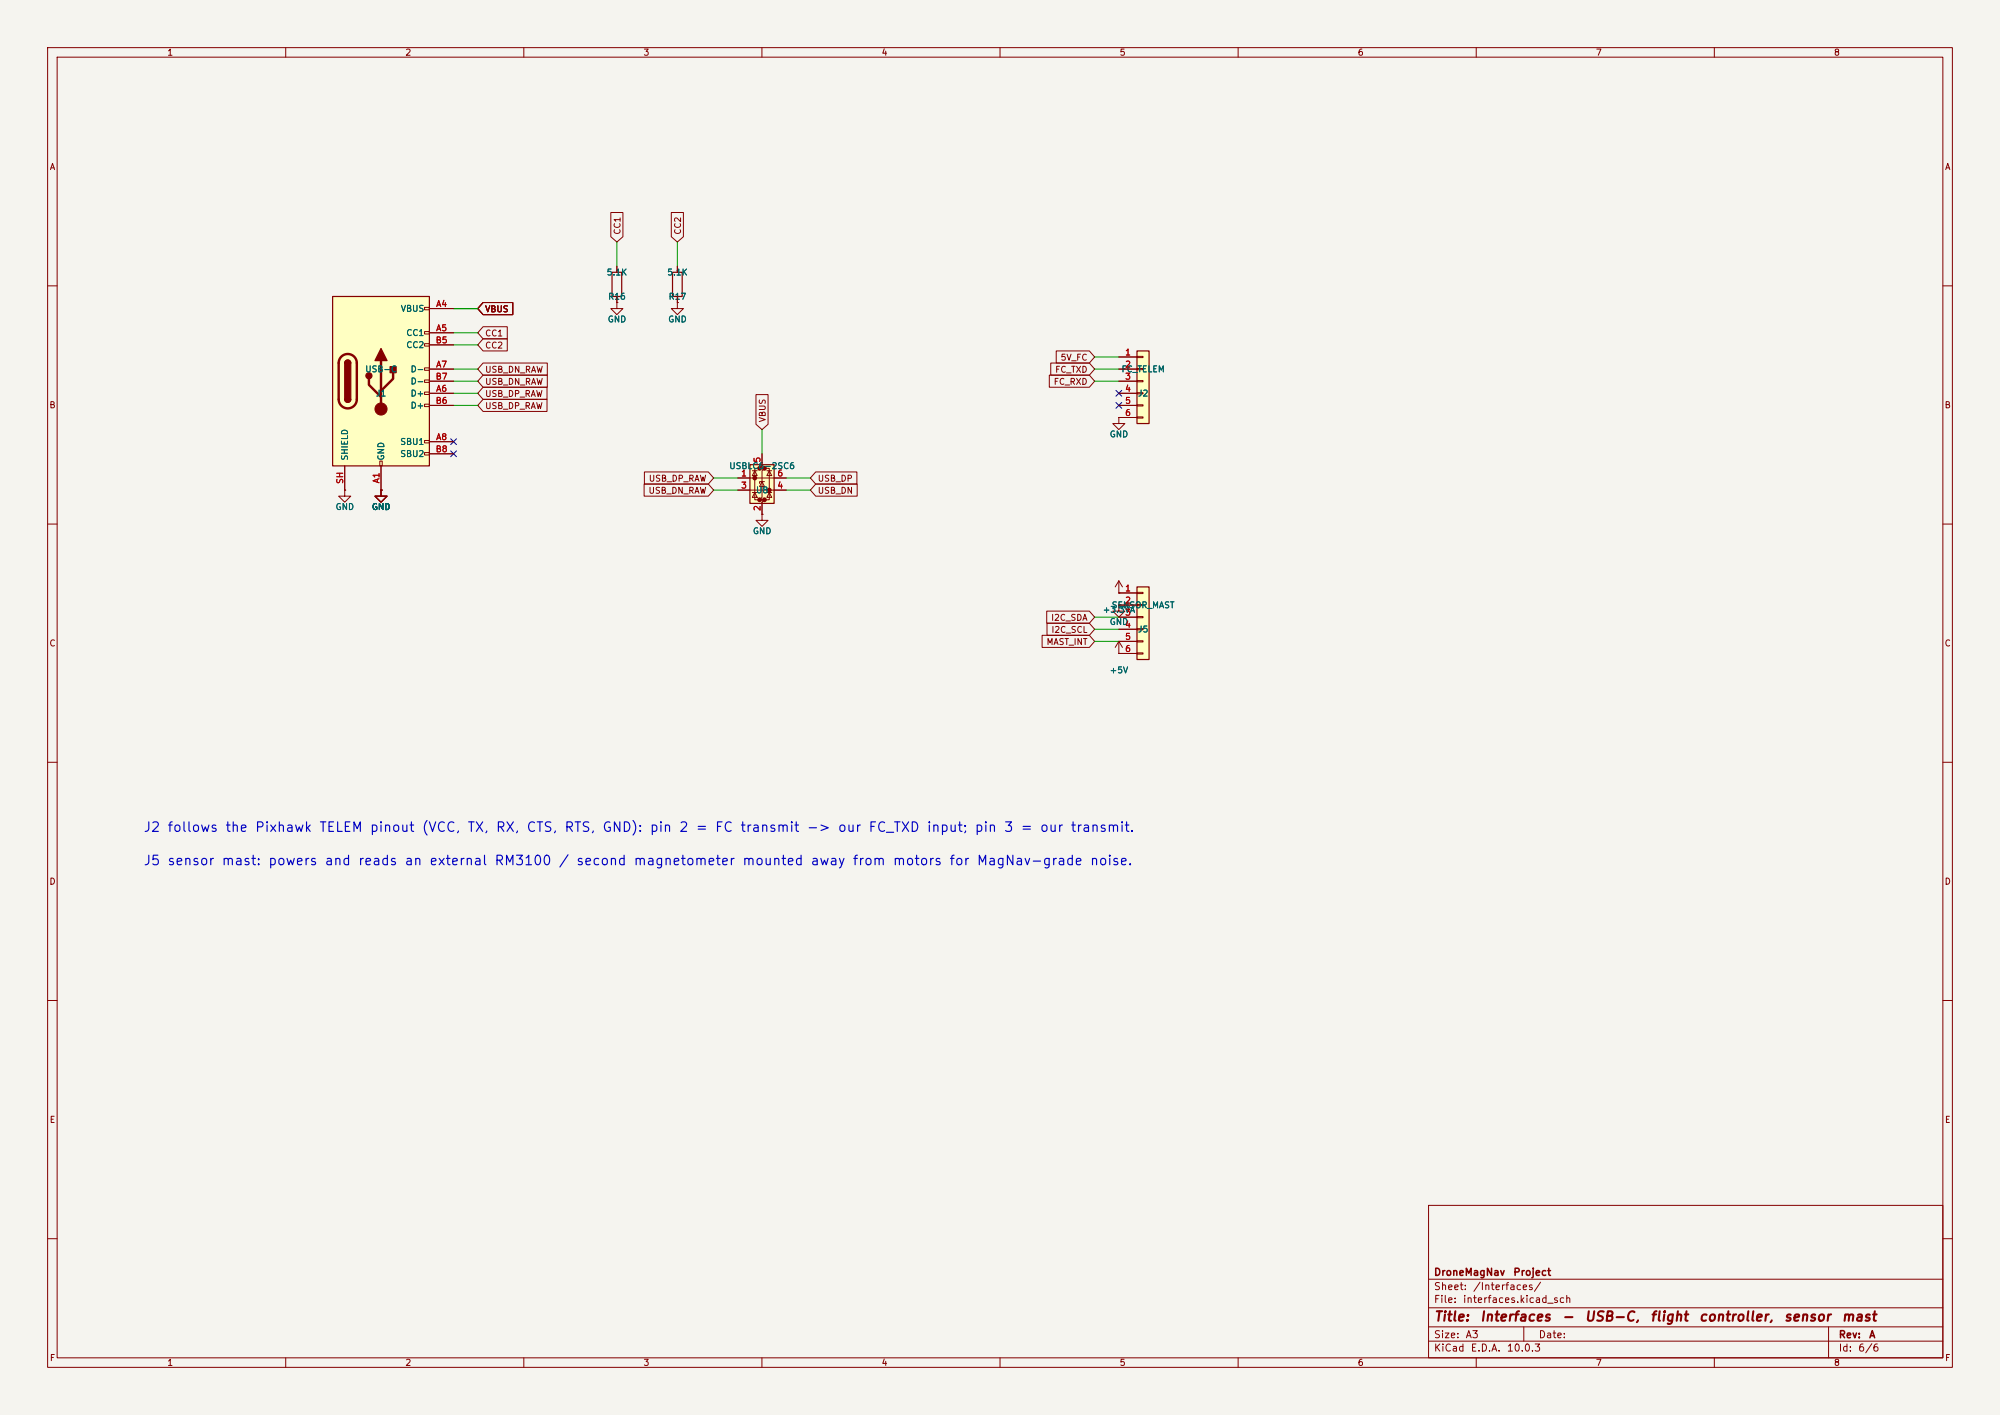
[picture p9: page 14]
GND; SENSOR_MAST GND; +5V GND; 6 U8 USBLC6-2SC6; GND +3.3VA GND; FC_TELEM GND A1; SBU2 B8 SHIELD SH; J1 USB-C; VBUS; USB_DP; MAST_INT 5V_FC; FC_TXD FC_RXD USB_DP_RAW; USB_DN_RAW; USB_DN; VBUS USB_DP_RAW; USB_DP_RAW; I2C_SDA; FC_TELEM; 1 2 3 4 5 6 U8 USBLC6-2SC6 1; 6 GND; +3.3VA GND J5; SENSOR_MAST 1 2 3 4 5 6; J1 USB-CGND A1; SBU1

I2C_SCL USB_DN_RAW J2 follows the Pixhawk TELEM pinout (VCC, TX, RX, CTS, RTS, GND): pin 2 = FC transmit -> our FC_TXD input; pin 3 = our transmit.

J5 sensor mast: powers and reads an external RM3100 / second magnetometer mounted away from motors for MagNav-grade noise. GND

DroneMagNav Project
Sheet: /Interfaces/
File: interfaces.kicad_sch
Title: Interfaces - USB-C, flight controller, sensor mast

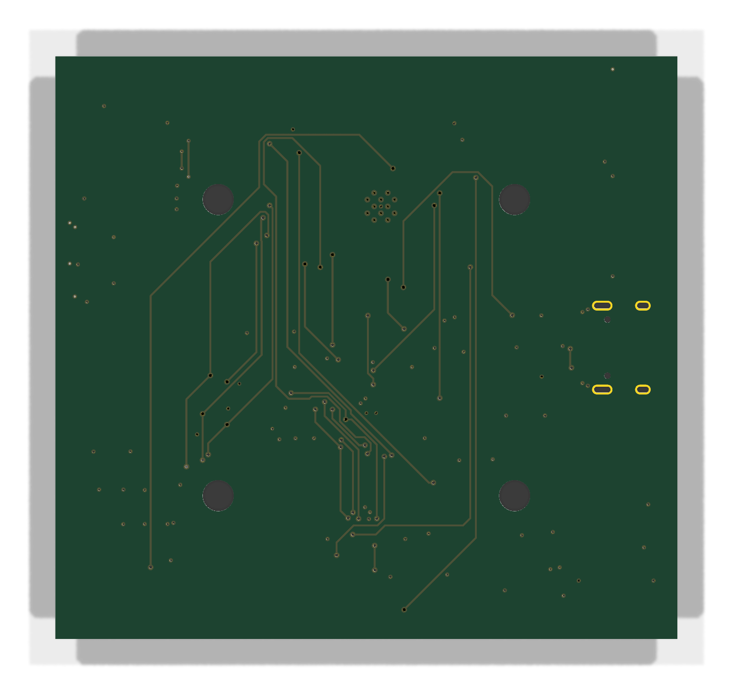
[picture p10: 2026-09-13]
hardware/dronemagnav/board-bottom.png

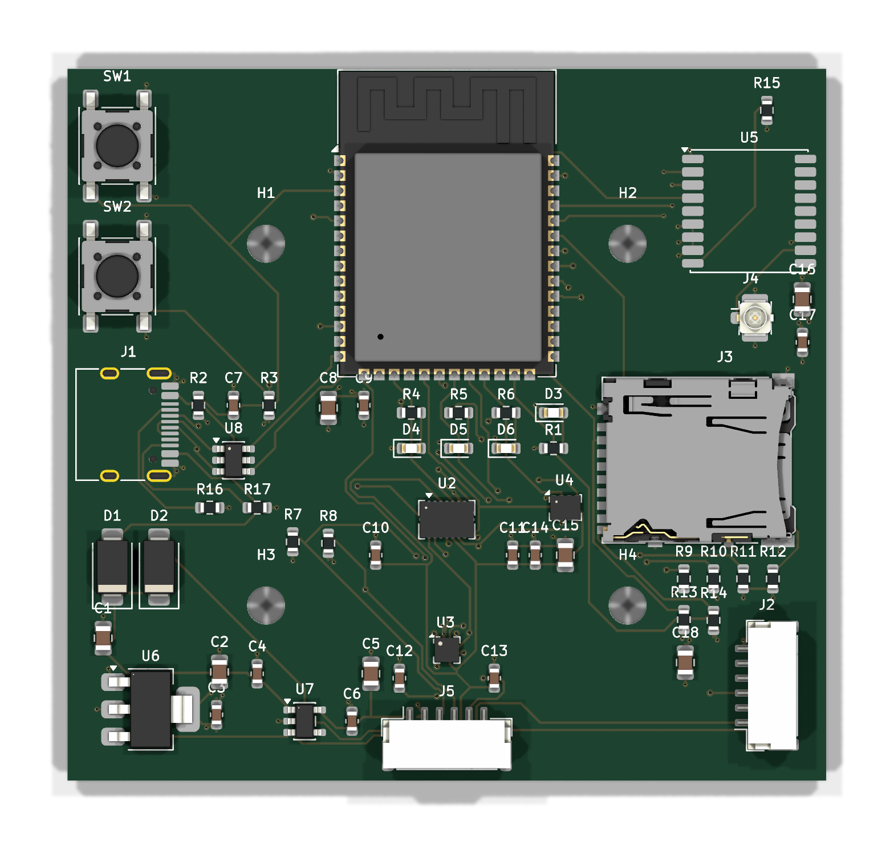
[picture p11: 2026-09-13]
hardware/dronemagnav/board-top.png

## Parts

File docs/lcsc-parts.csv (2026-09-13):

MPN | LCSC | Status | Note
CL21 series|10uF | C15850 | jlc-matched | Samsung CL21A106KAYNNNE 10uF 25V X5R 0805 (Basic)
CL10 series|100nF | C14663 | jlc-matched | Yageo CC0603KRX7R9BB104 100nF 50V X7R 0603 (Basic)
CL10 series|1uF | C15849 | jlc-matched | Samsung CL10A105KB8NNNC 1uF 50V X5R 0603 (Basic)
SS14 | C2480 | jlc-matched | MDD SS14 Schottky SMA (Basic)
RC0603FR-071KL | C21190 | jlc-proposed | UNI-ROYAL 0603WAF1001T5E 1k 1% (Basic)
RC0603FR-0710KL | C25804 | jlc-proposed | UNI-ROYAL 0603WAF1002T5E 10k 1% (Basic)
RC0603FR-07330RL | C23138 | jlc-proposed | UNI-ROYAL 0603WAF3300T5E 330R 1% (Basic)
RC0603FR-074.7KL | C23162 | jlc-proposed | UNI-ROYAL 0603WAF4701T5E 4.7k 1% (Basic)
RC0603FR-075.1KL | C23186 | jlc-proposed | UNI-ROYAL 0603WAF5101T5E 5.1k 1% (Basic)
ESP32-S3-WROOM-1-N16R8 | C2913202 | jlc-matched | Espressif (Extended) - check stock at order time
BMI088 | C194919 | jlc-matched | Bosch (Extended) - check stock at order time
LIS3MDLTR | C478483 | jlc-proposed | ST (Extended)
BMP280 | C83291 | jlc-matched | Bosch (Extended)
MAX-M10S-00B | C5291404 | jlc-matched | u-blox MAX-M10S (Extended)
AMS1117-3.3 | C6186 | jlc-matched | AMS (Basic)
AP2112K-3.3TRG1 | C22365427 | jlc-proposed-alternative | MSKSEMI AP2112K-3.3TRG1(MS) second-source; Diodes original is C51118 if in stock
USBLC6-2SC6 | C2687116 | jlc-proposed-alternative | UMW USBLC6-2SC6 second-source; ST original is C7519 if in stock
TYPE-C-31-M-12 | C165948 | verify | HRO TYPE-C-31-M-12 16-pin USB-C 2.0 receptacle - confirm footprint before ordering
19-217/GHC-YR1S2/3T |  | pick | LED green 0603: search library for "0603 green" (e.g. any 0603 green 20 mA)
19-217/BHC-ZL1M2RY/3T |  | pick | LED blue 0603
19-217/Y2C-CQ2R2L/3T |  | pick | LED yellow 0603
PTS645SM43SMTR92 |  | pick | 6x6 mm SMD 4-pad tactile switch; if C&K not stocked pick an equivalent 6x6 SMD (check pad layout against SW_SPST_PTS645Sx43SMTR92)
SM06B-GHS-TB |  | pick | JST GH 6-pin horizontal SMD; search "SM06B-GHS-TB"; else global sourcing / consign
DM3AT-SF-PEJM5 |  | pick | Hirose microSD push-push; search "DM3AT-SF-PEJM5"; else global sourcing / consign
U.FL-R-SMT-1(10) |  | pick | Hirose U.FL; search "U.FL-R-SMT-1"; else global sourcing / consign

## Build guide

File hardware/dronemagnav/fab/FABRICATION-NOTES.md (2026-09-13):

# DroneMagNav rev A - fabrication and assembly notes

## Board
- Size 64.1 x 60.1 mm, 4 copper layers, 1.6 mm FR-4 (TG >= 150), 1 oz outer / 0.5 oz inner copper.
- Stackup: F.Cu signal / In1.Cu GND plane / In2.Cu +3V3 plane / B.Cu signal.
- Surface finish: ENIG (flat pads for the 0.5 mm-pitch BMI088 LGA and the USB-C receptacle).
- Solder mask green, silkscreen white, both sides. Mask clearance per Gerber files.
- Minimum track 0.20 mm, minimum clearance 0.15 mm, minimum hole 0.20 mm.
- Via sizes (diameter / drill, mm): 0.40/0.20, 0.45/0.20, 0.60/0.30; 145 vias total.
- Plated holes (drill, mm): 0.60, 0.65, 3.20; four 3.2 mm mounting holes on the 30.5 mm Pixhawk pattern are non-plated.
- Controlled impedance: the GNSS RF trace from U.FL J4 to U5 RF_IN is 50 ohm single-ended over the In1 ground plane. Please adjust the trace width to your stackup if it differs from 0.2 mm prepreg between F.Cu and In1.Cu.
- Copper keep-out under the ESP32-S3-WROOM-1 antenna (top edge, x 106-154 mm) on all layers: do not add copper, thieving or fiducials there.

## Vias in pads (IMPORTANT)
- 74 power vias were moved out of their pads into dog-bone stubs, so the vast majority of pads carry no via.
- 3 vias remain inside small pads because the surrounding routing leaves no room. These MUST be filled and capped (IPC-4761 Type VII, epoxy fill + plated cap) or at minimum plugged and tented on the component side, otherwise solder wicks into the hole and the joint is starved:
    - J3 pad 4 (+3V3), via 0.40/0.20 mm at (143.075, 133.725) mm, pad 0.70 x 1.20 mm
    - U2 pad 2 (GND), via 0.40/0.20 mm at (129.000, 136.740) mm, pad 0.25 x 0.68 mm
    - U2 pad 4 (GND), via 0.40/0.20 mm at (130.000, 136.740) mm, pad 0.25 x 0.68 mm
- 2 vias sit inside large thermal pads / tabs (normal practice; tented or filled, either is fine):
    - U1 pad 41 (GND) at (128.500, 115.460) mm
    - U6 pad 2 (+3V3) at (108.150, 154.000) mm

## Assembly
- All components are on the top side (see dronemagnav-pos.csv, mm, origin = drill/place origin).
- Reflow profile per BMI088 / LIS3MDL / BMP280 datasheets (lead-free, peak <= 260 C). Do not clean the sensors ultrasonically.
- U1 ESP32-S3-WROOM-1: keep the antenna end overhanging the board edge free of solder and fixtures.
- J3 microSD (Hirose DM3AT) and J1 USB-C: hand-inspect the shield pads for bridges.
- U3 LIS3MDL magnetometer: keep away from magnetised tools and fixtures; no magnetic nozzles or trays during placement.
- Fiducials: none on the board; use the mounting holes as datums.

## Files
- gerbers/*.gtl .g1 .g2 .gbl .gts .gbs .gtp .gbp .gto .gbo .gm1  copper, mask, paste, silk, edge
- gerbers/dronemagnav.drl + dronemagnav-drl_map.gbr  Excellon drill (all plated except the 3.2 mm mounting holes) and drill map
- gerbers/dronemagnav-job.gbrjob  Gerber job file with the stackup
- dronemagnav-pos.csv  pick-and-place (KiCad format)
- dronemagnav-cpl-jlcpcb.csv + dronemagnav-bom-jlcpcb.csv  the same placement list and BOM in JLCPCB's upload format (LCSC column left blank: let the uploader match on MPN and confirm)
- dronemagnav-centroid-pcbway.csv + dronemagnav-bom-pcbway.csv/.xlsx  PCBWay-format centroid (mm, origin bottom-left, Y up, pad-1 position, T/B layer) and BOM (PCBWay template columns)
- ../docs/BOM.csv  bill of materials with manufacturer part numbers

Generated by tools/make_fab.py from the routed board; via/pad numbers from tools/fab_audit.py.

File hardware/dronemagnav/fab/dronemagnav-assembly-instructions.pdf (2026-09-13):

# DroneMagNav rev A - assembly instructions

Magnetic-anomaly navigation module, 64 x 60 mm, 4 layers. 56 SMD parts, all on the TOP side, no through-hole parts. Files: Gerber ZIP (with FABRICATION-NOTES.md), BOM (PCBWay template), centroid file (mm, origin bottom-left, pad-1 position). This document: orientation and handling rules, IC programming, functional test, and the top assembly drawing (appendix).

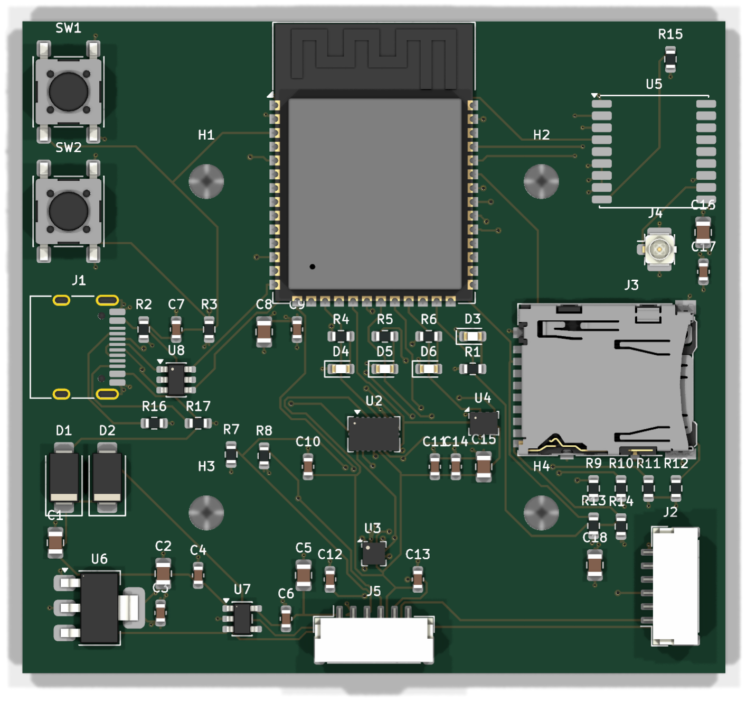
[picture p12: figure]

Top side, as assembled (3-D render from the CAD data).

## 1. Orientation and polarity

Rotations in the centroid file follow the KiCad / Altium convention (degrees, counter-clockwise positive, 0 deg = library orientation). Pad-1 coordinates are given for every part; the F.Fab layer in the appendix shows pin-1 marks and pad outlines with numbers.
Ref | Part | Orientation / polarity
U1 | ESP32-S3-WROOM-1-N16R8 | Pin 1 = pad at the corner marked on F.Fab. The PCB antenna end of the module overhangs the TOP board edge (x 106-154 mm keep-out): do not clamp, solder or fixture that end. MSL 3: bake 24 h / 125 C if the bag was open > 168 h.
U2 | BMI088 LGA-16, 0.5 mm pitch | Pin-1 dot on the package corner marked on F.Fab. Pads under the body: solder-paste stencil 0.1 mm, X-ray or AOI check recommended. Pads 2 and 4 contain filled-and-capped vias.
U3 | LIS3MDL LGA-12 (magnetometer) | Pin-1 mark on F.Fab. NO magnetised tools, nozzles or trays near this part; keep it away from magnets during and after assembly.
U4 | BMP280 LGA-8 | Pin-1 mark on F.Fab. Do not cover the vent hole with flux residue.
U5 | MAX-M10S LCC-18 | Pin 1 marked on F.Fab (chamfered corner of the module). RF pin 11 faces U.FL J4.
U6 | AMS1117-3.3 SOT-223 | Tab = pin 2 (+3V3 output).
U7 / U8 | SOT-23-5 / SOT-23-6 | Pin 1 per F.Fab mark.
D1, D2 | SS14 SMA Schottky | Cathode band = pad 1 (silkscreen bar).
D3-D6 | 0603 LEDs: D3 green, D4 green, D5 blue, D6 yellow | Cathode = pad 1 (silkscreen arrow / bar on the cathode side).
J1 | USB-C HRO TYPE-C-31-M-12 | Keyed by the shell; opening faces the LEFT board edge.
J2, J5 | JST-GH SM06B-GHS-TB, 6-pin | Pin 1 marked on silkscreen; openings face the board edge.
J3 | microSD Hirose DM3AT | Card slot faces the RIGHT board edge; check shield pads for bridges.
J4 | U.FL-R-SMT-1 | Centre pin = signal, keep pad 1 free of flux residue.

Ref | Part | Orientation / polarity
SW1, SW2 | Tactile 6 x 6 mm | Symmetric, no polarity.
R*, C* | 0603 / 0805 | No polarity.

## 2. Process and handling

- Lead-free reflow per the sensor datasheets: peak 245-260 C, max 30 s above 217 C. No wave, no hand-soldering of U2/U3/U4.
- No ultrasonic cleaning (MEMS sensors U2, U3, U4). No-clean flux preferred.
- No magnetised tooling near U3 (magnetometer). Do not store finished boards on magnetic trays.
- PCB: 4-layer, ENIG, 1.6 mm, vias filled and capped (three vias sit inside SMD pads: U2 pads 2/4, J3 pad 4). Board edge clearance 0.5 mm; four 3.2 mm NPTH mounting holes.
- Nothing may be placed, printed or glued in the antenna keep-out at the top edge.
- Inspect J1 (USB-C) and J3 (microSD) shield pads and the U1 module pads for bridges; the U2 LGA joints by X-ray if available.

## 3. IC programming

No pre-programming of any part is required before assembly: the ESP32-S3 module boots into its factory ROM loader and is flashed over the USB-C connector after assembly. If the programming service is ordered, flash the supplied image dronemagnav-firmware.factory.bin (bootloader + partition table + application, 1.16 MB) as follows:
Step | Action
1 | Connect the board to a PC with a USB-C data cable (5 V from USB is enough; no other supply).
2 | Hold BOOT (SW2), press and release RESET (SW1), release BOOT. The board enumerates as a USB serial port (Espressif USB JTAG/serial debug unit).
3 | With Python 3 and pip install esptool (any version >= 4), run the command below with the port name of that device.
4 | Press RESET. The green PWR LED (D3) is on; the serial port re-enumerates and prints the boot log (see section 4). Done.

esptool --chip esp32s3 --port COM5 --baud 921600 write-flash 0x0 dronemagnav-firmware.factory.bin
SHA-256 of the image is listed in firmware/release/ in the repository. The image does not depend on the microSD card; the card only carries map data.

## 4. Functional test (after programming)

Equipment: USB-C cable, PC with a serial terminal (115200 baud), multimeter, a phone or laptop with WiFi, optionally a FAT32 microSD card and a passive GNSS antenna with U.FL.
# | Test | Pass criteria

T1 | Visual / AOI | No bridges, all 56 parts present and oriented per section 1.
T2 | Power-up on USB 5 V | Green PWR LED D3 on. Supply current 60-250 mA (WiFi access point running). FAIL if < 20 mA or > 400 mA.
T3 | Rails | +3V3 at U6 pin 2 (tab): 3.30 +/- 0.10 V. +3.3VA at U7 pin 5: 3.30 +/- 0.10 V.
T4 | USB enumeration | A USB serial device appears on the PC within 3 s of RESET.
T5 | Boot log (serial 115200) | Lines [imu] ok, [mag] ok, [baro] ok must appear. [sd] ok when a FAT32 card is inserted (without a card [sd] FAIL is expected and acceptable). [web] AP DroneMagNav must appear.
T6 | WiFi | SSID DroneMagNav visible; password magnav123; http://192.168.4.1/ loads the map page; http://192.168.4.1/api/status returns JSON with non-zero magnetic field and pressure values.
T7 | Buttons | RESET repeats the boot log. BOOT held during RESET stops the boot log (download mode) - then RESET again to resume.
T8 | GNSS (optional) | Antenna on J4, board near a window: blue FIX LED D5 on within 3 min; /api/status shows a latitude/longitude.
T9 | LEDs D4 NAV and D6 LINK | Off during this test (they need a flight controller / navigation mode). They must not be stuck on.

Record per board: serial port seen, T2 current, T3 voltages, T5 log lines, T6 result. A board passing T1-T7 is a good unit.

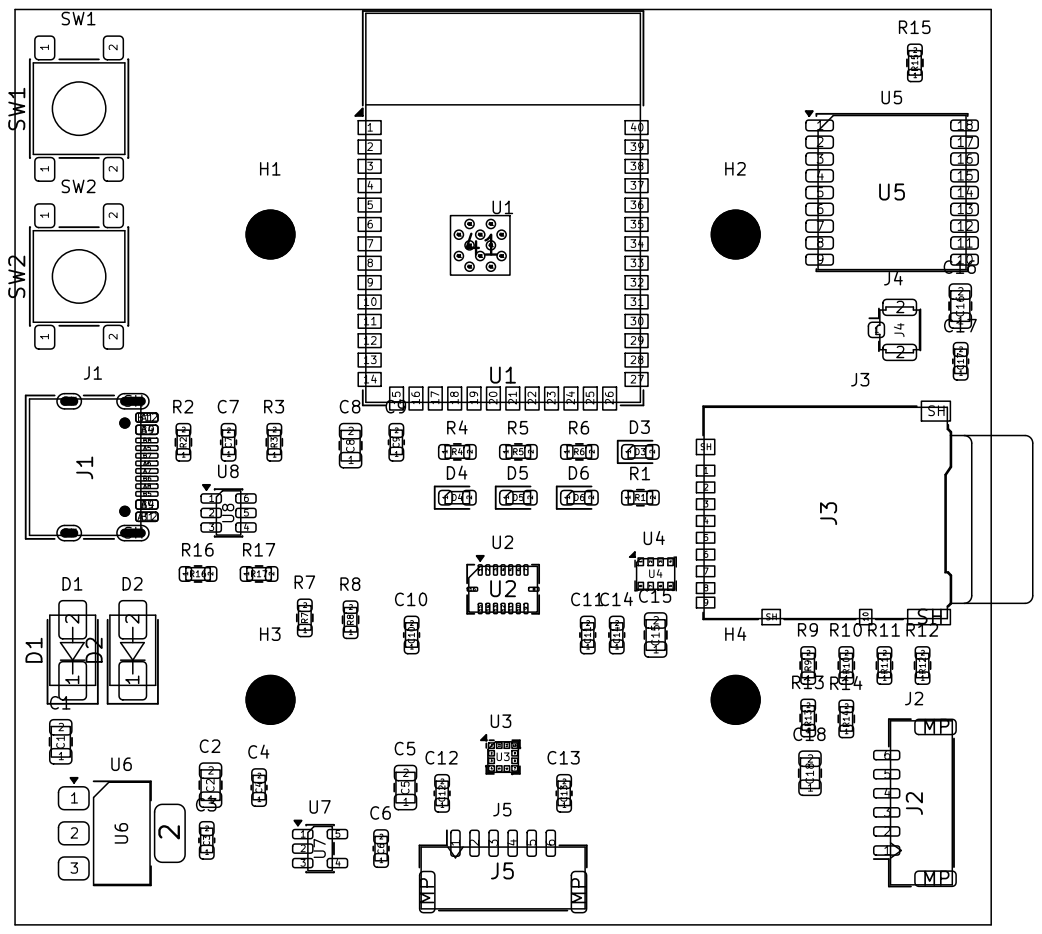
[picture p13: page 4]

Top assembly drawing: F.Fab + F.Silkscreen + Edge.Cuts, all parts top side
DroneMagNav Project
Sheet:
File: dronemagnav.kicad_pcb
Title: DroneMagNav - magnetic anomaly navigation board
KiCad E.D.A. 10.0.3

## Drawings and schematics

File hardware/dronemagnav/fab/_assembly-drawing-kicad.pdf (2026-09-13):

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

Size: A4 | Rev: A
KiCad E.D.A. 10.0.3 | Id: 1/1

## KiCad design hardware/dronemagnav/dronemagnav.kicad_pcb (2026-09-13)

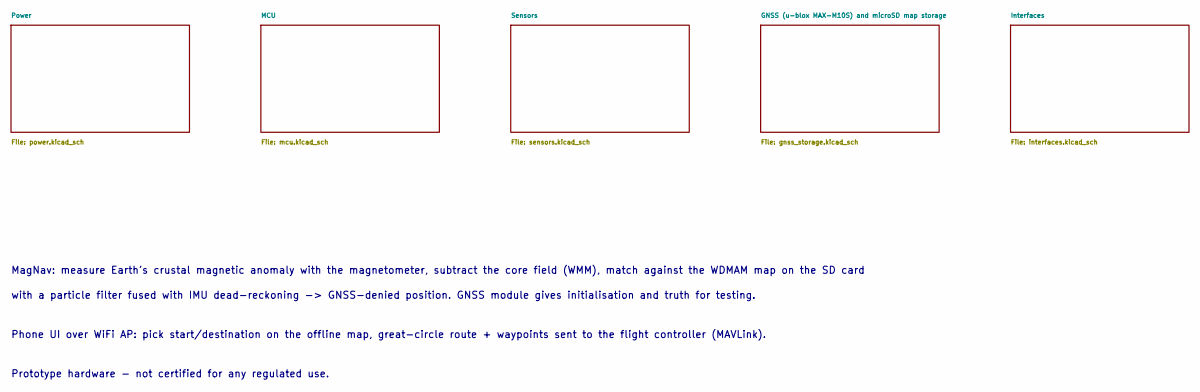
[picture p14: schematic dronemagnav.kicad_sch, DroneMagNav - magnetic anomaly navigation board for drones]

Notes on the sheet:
MagNav: measure Earth's crustal magnetic anomaly with the magnetometer, subtract the core field (WMM), match against the WDMAM map on the SD card
with a particle filter fused with IMU dead-reckoning -> GNSS-denied position. GNSS module gives initialisation and truth for testing.
Phone UI over WiFi AP: pick start/destination on the offline map, great-circle route + waypoints sent to the flight controller (MAVLink).
Prototype hardware - not certified for any regulated use.

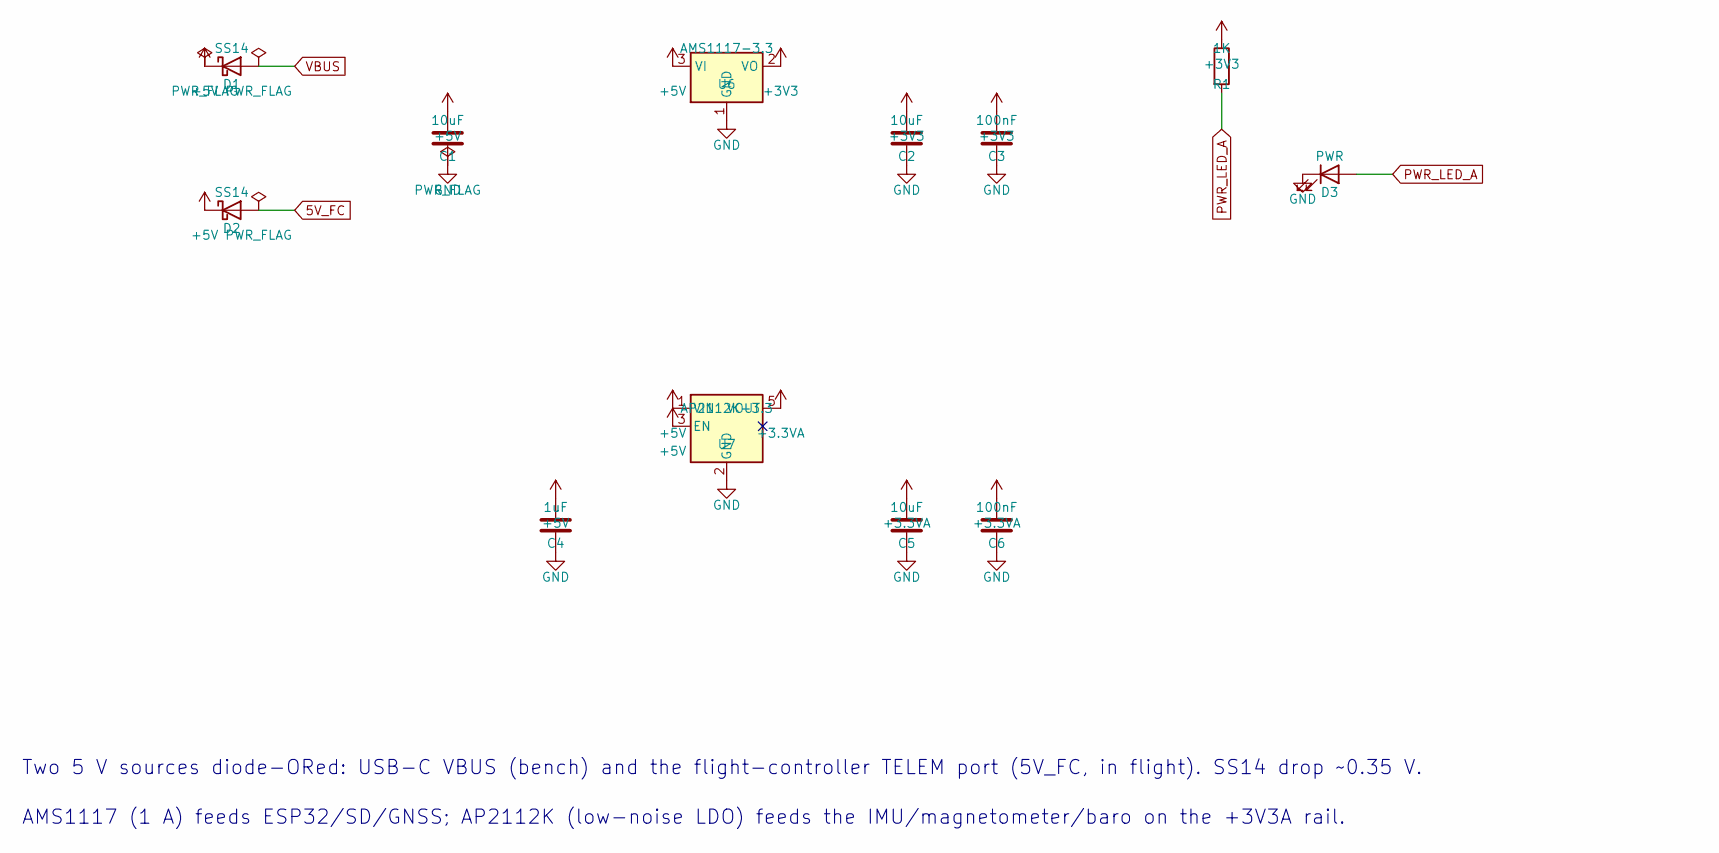
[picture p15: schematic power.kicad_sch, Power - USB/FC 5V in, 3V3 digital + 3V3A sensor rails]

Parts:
C1, C2, C5: 10uF; C_0805_2012Metric
C3, C6: 100nF; C_0603_1608Metric
C4: 1uF; C_0603_1608Metric
D1, D2: SS14; D_SMA
D3: PWR; LED_0603_1608Metric
R1: 1K; R_0603_1608Metric
U6: AMS1117-3.3; SOT-223-3_TabPin2
U7: AP2112K-3.3; SOT-23-5

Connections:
+3.3VA: C5.1, C6.1, U7.5 (VOUT); also elsewhere on the board
+3V3: C2.1, C3.1, R1.1, U6.2 (VO); also elsewhere on the board
PWR_LED_A: D3.2 (A), R1.2

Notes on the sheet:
Two 5 V sources diode-ORed: USB-C VBUS (bench) and the flight-controller TELEM port (5V_FC, in flight). SS14 drop ~0.35 V.
AMS1117 (1 A) feeds ESP32/SD/GNSS; AP2112K (low-noise LDO) feeds the IMU/magnetometer/baro on the +3V3A rail.

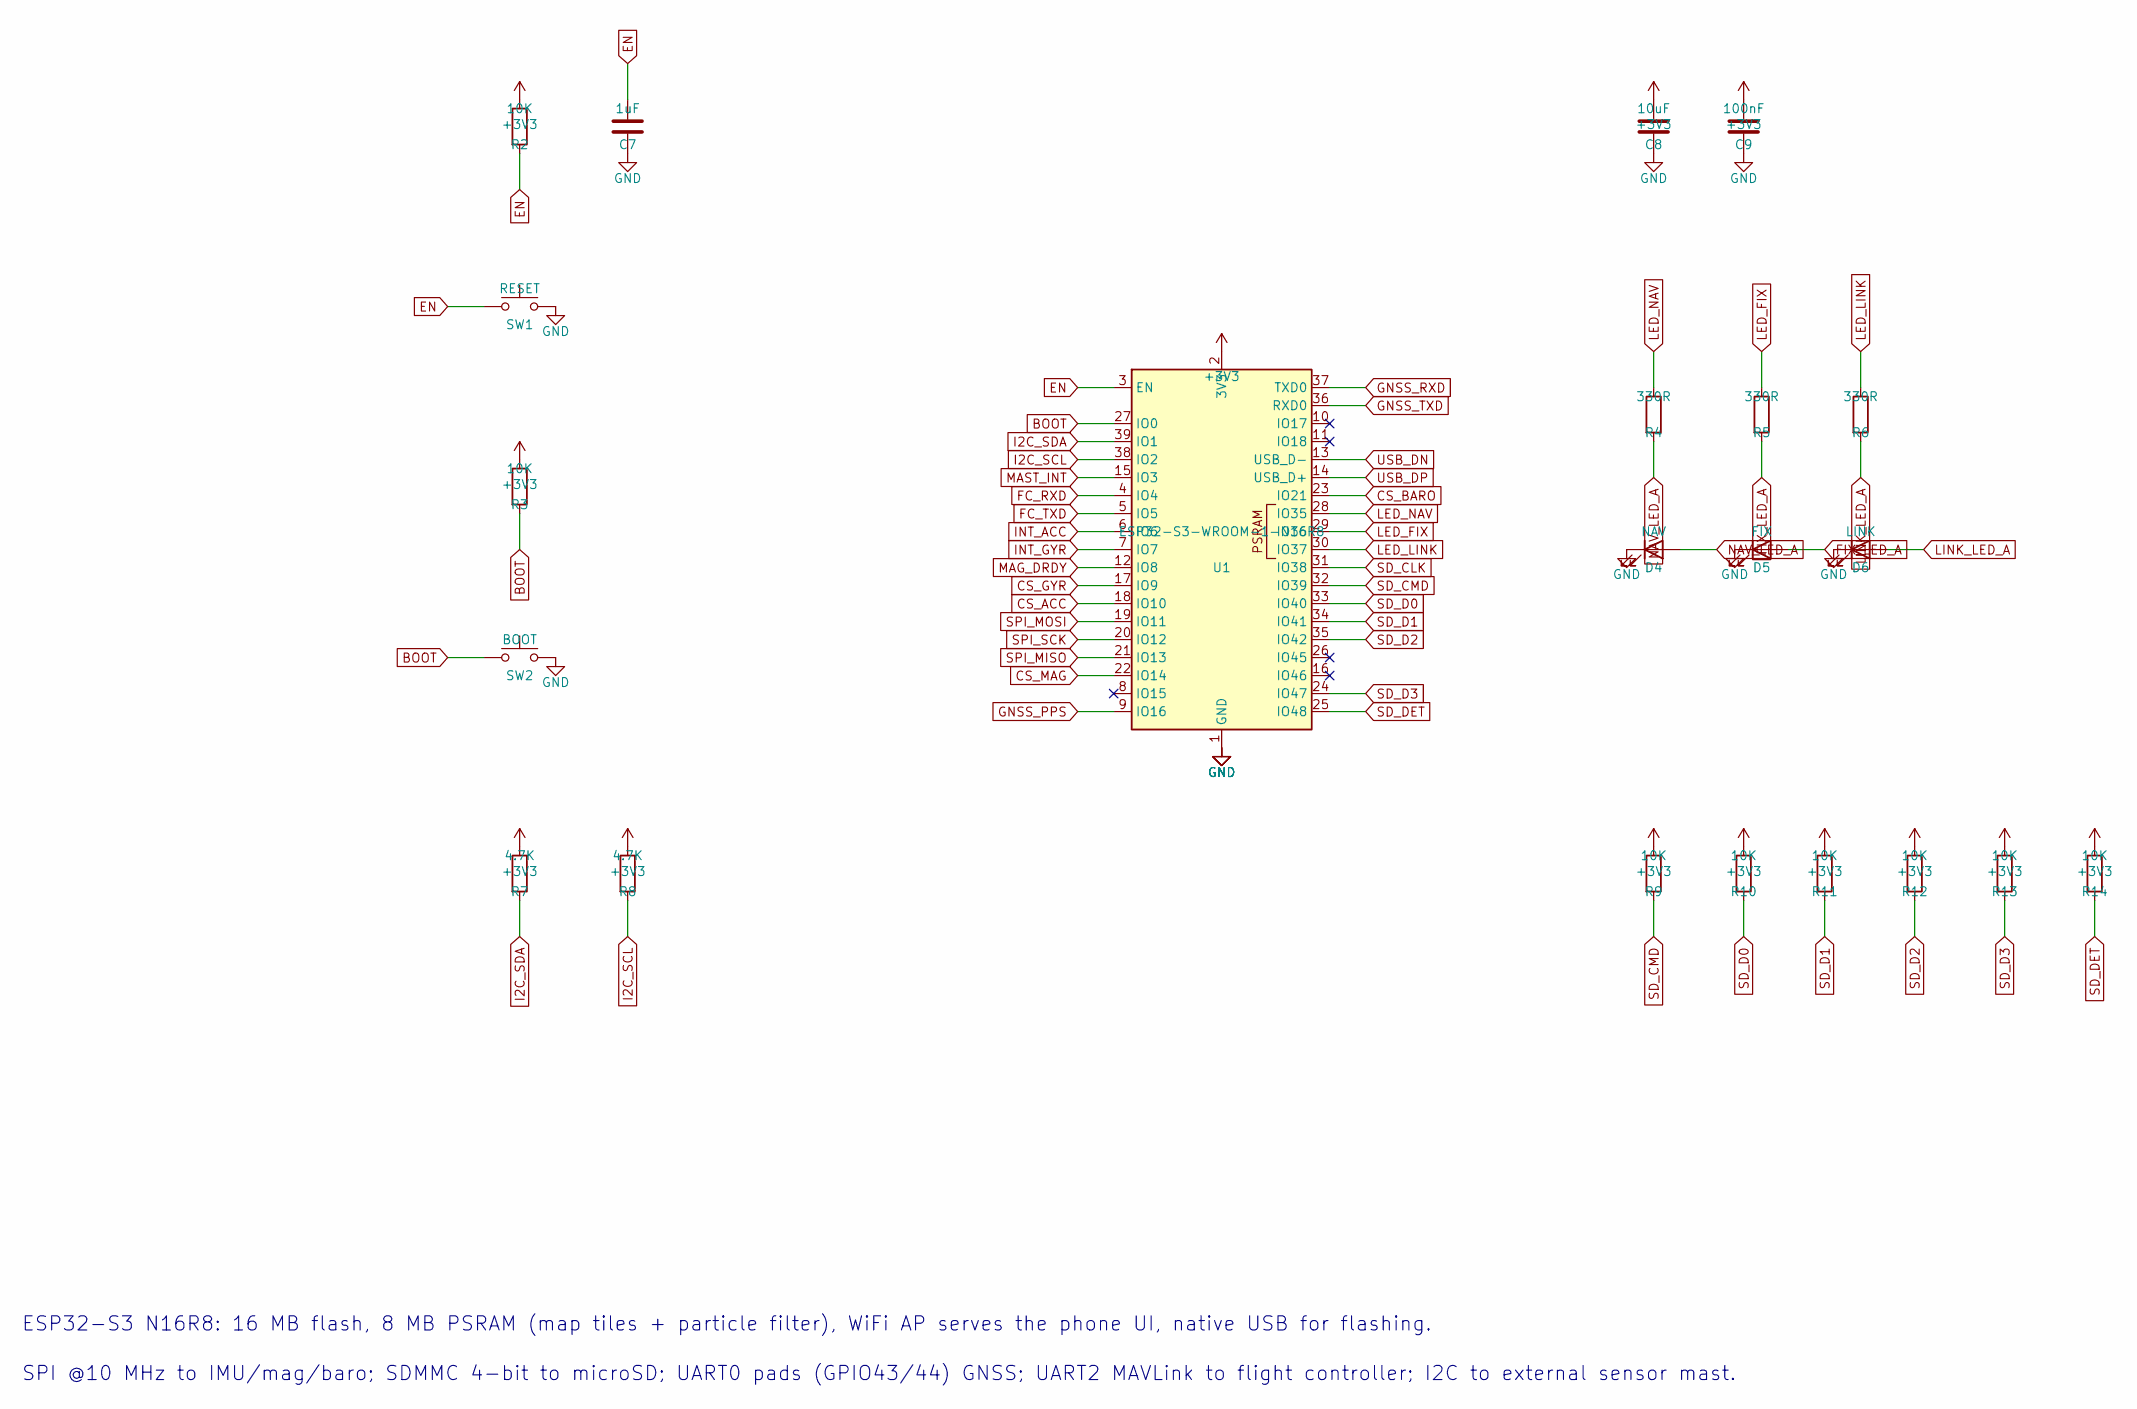
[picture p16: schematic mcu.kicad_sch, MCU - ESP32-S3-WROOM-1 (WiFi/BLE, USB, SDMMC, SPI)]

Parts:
C7: 1uF; C_0603_1608Metric
C8: 10uF; C_0805_2012Metric
C9: 100nF; C_0603_1608Metric
D4: NAV; LED_0603_1608Metric
D5: FIX; LED_0603_1608Metric
D6: LINK; LED_0603_1608Metric
R2, R3, R9, R10, R11, R12, R13, R14: 10K; R_0603_1608Metric
R4, R5, R6: 330R; R_0603_1608Metric
R7, R8: 4.7K; R_0603_1608Metric
SW1: RESET; SW_SPST_PTS645Sx43SMTR92
SW2: BOOT; SW_SPST_PTS645Sx43SMTR92
U1: ESP32-S3-WROOM-1-N16R8; ESP32-S3-WROOM-1

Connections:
+3V3: C8.1, C9.1, R2.1, R3.1, R7.1, R8.1, R9.1, R10.1, R11.1, R12.1, R13.1, R14.1, U1.2 (3V3); also elsewhere on the board
BOOT: R3.2, SW2.1, U1.27 (IO0)
CS_ACC: U1.18 (IO10); also elsewhere on the board
CS_BARO: U1.23 (IO21); also elsewhere on the board
CS_GYR: U1.17 (IO9); also elsewhere on the board
CS_MAG: U1.22 (IO14); also elsewhere on the board
EN: C7.1, R2.2, SW1.1, U1.3 (EN)
FC_RXD: U1.4 (IO4); also elsewhere on the board
FC_TXD: U1.5 (IO5); also elsewhere on the board
FIX_LED_A: D5.2 (A), R5.2
GNSS_PPS: U1.9 (IO16); also elsewhere on the board
GNSS_RXD: U1.37 (TXD0); also elsewhere on the board
GNSS_TXD: U1.36 (RXD0); also elsewhere on the board
I2C_SCL: R8.2, U1.38 (IO2); also elsewhere on the board
I2C_SDA: R7.2, U1.39 (IO1); also elsewhere on the board
INT_ACC: U1.6 (IO6); also elsewhere on the board
INT_GYR: U1.7 (IO7); also elsewhere on the board
LED_FIX: R5.1, U1.29 (IO36)
LED_LINK: R6.1, U1.30 (IO37)
LED_NAV: R4.1, U1.28 (IO35)
LINK_LED_A: D6.2 (A), R6.2
MAG_DRDY: U1.12 (IO8); also elsewhere on the board
MAST_INT: U1.15 (IO3); also elsewhere on the board
NAV_LED_A: D4.2 (A), R4.2
SD_CLK: U1.31 (IO38); also elsewhere on the board
SD_CMD: R9.2, U1.32 (IO39); also elsewhere on the board
SD_D0: R10.2, U1.33 (IO40); also elsewhere on the board
SD_D1: R11.2, U1.34 (IO41); also elsewhere on the board
SD_D2: R12.2, U1.35 (IO42); also elsewhere on the board
SD_D3: R13.2, U1.24 (IO47); also elsewhere on the board
SD_DET: R14.2, U1.25 (IO48); also elsewhere on the board
SPI_MISO: U1.21 (IO13); also elsewhere on the board
SPI_MOSI: U1.19 (IO11); also elsewhere on the board
SPI_SCK: U1.20 (IO12); also elsewhere on the board
USB_DN: U1.13 (USB_D-); also elsewhere on the board
USB_DP: U1.14 (USB_D+); also elsewhere on the board

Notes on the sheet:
ESP32-S3 N16R8: 16 MB flash, 8 MB PSRAM (map tiles + particle filter), WiFi AP serves the phone UI, native USB for flashing.
SPI @10 MHz to IMU/mag/baro; SDMMC 4-bit to microSD; UART0 pads (GPIO43/44) GNSS; UART2 MAVLink to flight controller; I2C to external sensor mast.

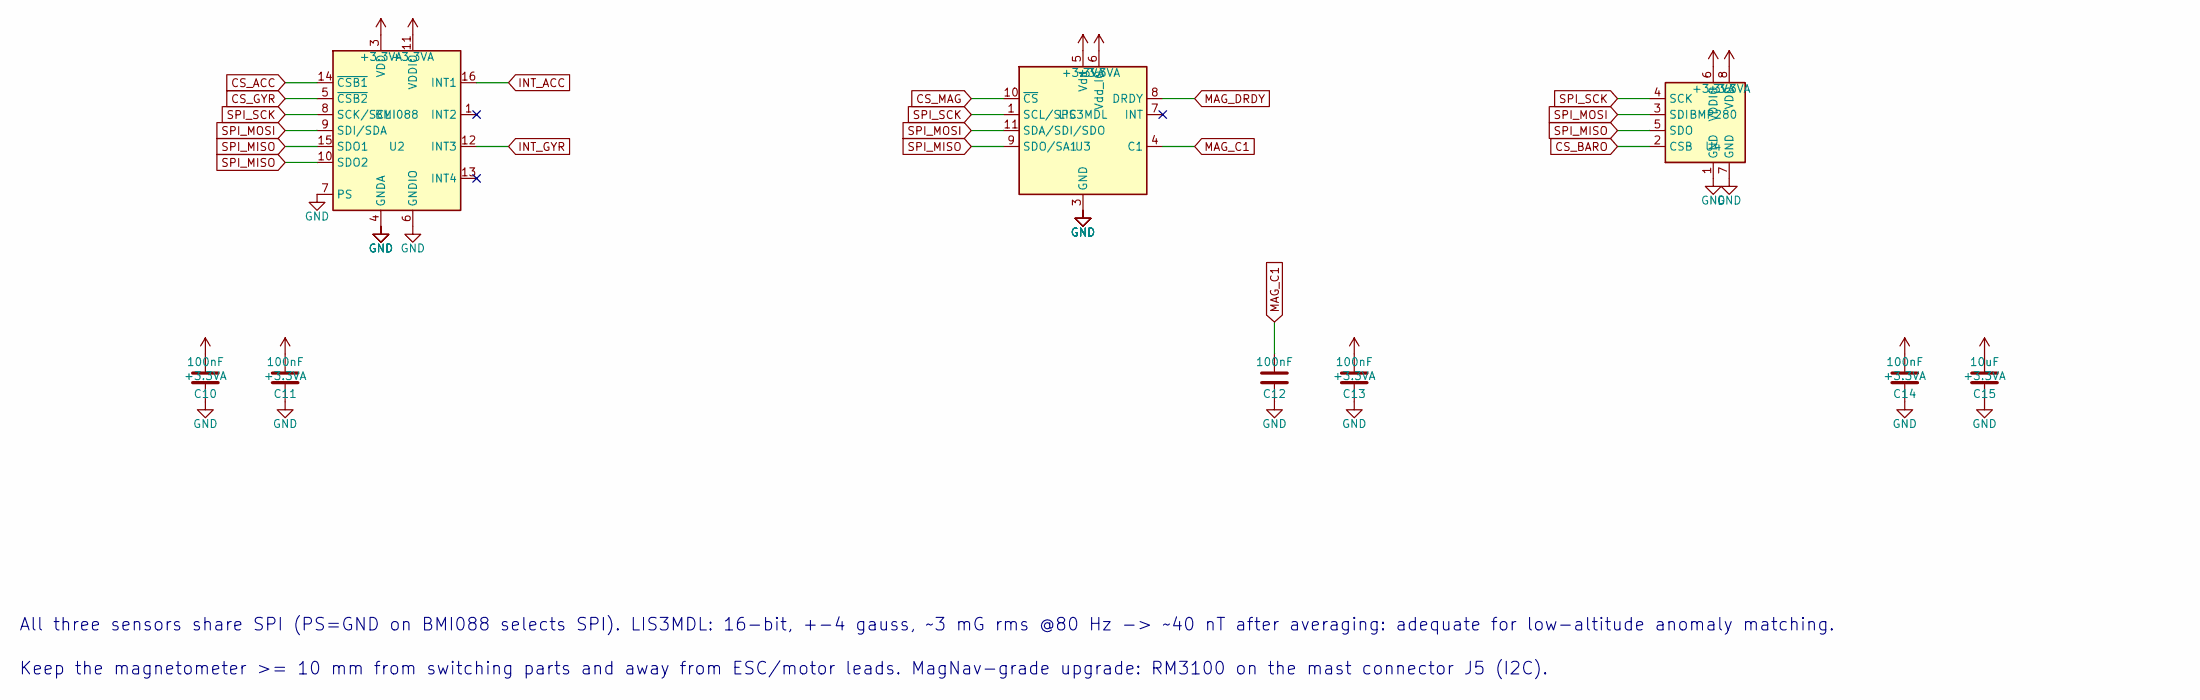
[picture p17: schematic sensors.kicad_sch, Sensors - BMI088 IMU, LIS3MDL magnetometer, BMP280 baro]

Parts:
C10, C11, C12, C13, C14: 100nF; C_0603_1608Metric
C15: 10uF; C_0805_2012Metric
U2: BMI088; Bosch_LGA-16_4.5x3mm_P0.5mm_LayoutBorder7x1y_ClockwisePinNu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
U3: LIS3MDL; LGA-12_2x2mm_P0.5mm
U4: BMP280; Bosch_LGA-8_2x2.5mm_P0.65mm_ClockwisePinNumbering

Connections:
+3.3VA: C10.1, C11.1, C13.1, C14.1, C15.1, U2.3 (VDD), U2.11 (VDDIO), U3.5 (Vdd), U3.6 (Vdd_IO), U4.6 (VDDIO), U4.8 (VDD); also elsewhere on the board
CS_ACC: U2.14 (~CSB1); also elsewhere on the board
CS_BARO: U4.2 (CSB); also elsewhere on the board
CS_GYR: U2.5 (~CSB2); also elsewhere on the board
CS_MAG: U3.10 (~CS); also elsewhere on the board
INT_ACC: U2.16 (INT1); also elsewhere on the board
INT_GYR: U2.12 (INT3); also elsewhere on the board
MAG_C1: C12.1, U3.4 (C1)
MAG_DRDY: U3.8 (DRDY); also elsewhere on the board
SPI_MISO: U2.10 (SDO2), U2.15 (SDO1), U3.9 (SDO/SA1), U4.5 (SDO); also elsewhere on the board
SPI_MOSI: U2.9 (SDI/SDA), U3.11 (SDA/SDI/SDO), U4.3 (SDI); also elsewhere on the board
SPI_SCK: U2.8 (SCK/SCL), U3.1 (SCL/SPC), U4.4 (SCK); also elsewhere on the board

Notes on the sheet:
All three sensors share SPI (PS=GND on BMI088 selects SPI). LIS3MDL: 16-bit, +-4 gauss, ~3 mG rms @80 Hz -> ~40 nT after averaging: adequate for low-altitude anomaly matching.
Keep the magnetometer >= 10 mm from switching parts and away from ESC/motor leads. MagNav-grade upgrade: RM3100 on the mast connector J5 (I2C).

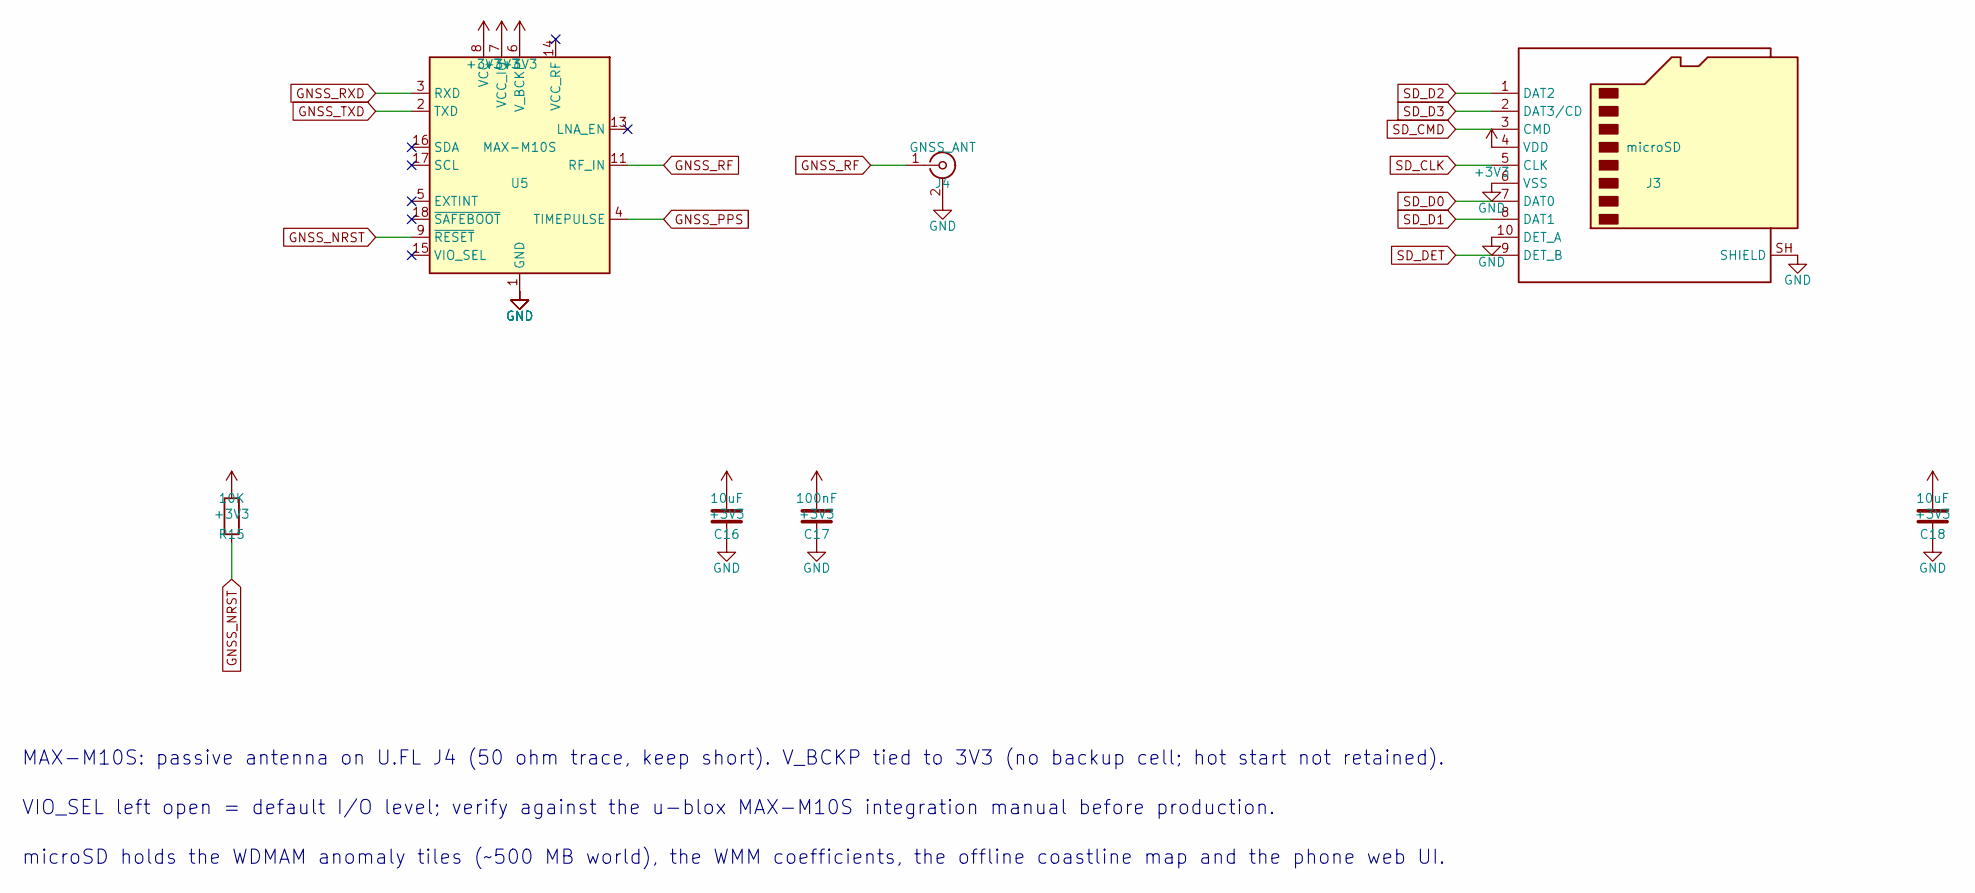
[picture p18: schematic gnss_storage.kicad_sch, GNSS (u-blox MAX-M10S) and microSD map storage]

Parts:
C16, C18: 10uF; C_0805_2012Metric
C17: 100nF; C_0603_1608Metric
J3: microSD; microSD_HC_Hirose_DM3AT-SF-PEJM5
J4: GNSS_ANT; U.FL_Hirose_U.FL-R-SMT-1_Vertical
R15: 10K; R_0603_1608Metric
U5: MAX-M10S; ublox_MAX

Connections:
+3V3: C16.1, C17.1, C18.1, J3.4 (VDD), R15.1, U5.6 (V_BCKP), U5.7 (VCC_IO), U5.8 (VCC); also elsewhere on the board
GNSS_NRST: R15.2, U5.9 (~RESET)
GNSS_PPS: U5.4 (TIMEPULSE); also elsewhere on the board
GNSS_RF: J4.1 (In), U5.11 (RF_IN)
GNSS_RXD: U5.3 (RXD); also elsewhere on the board
GNSS_TXD: U5.2 (TXD); also elsewhere on the board
SD_CLK: J3.5 (CLK); also elsewhere on the board
SD_CMD: J3.3 (CMD); also elsewhere on the board
SD_D0: J3.7 (DAT0); also elsewhere on the board
SD_D1: J3.8 (DAT1); also elsewhere on the board
SD_D2: J3.1 (DAT2); also elsewhere on the board
SD_D3: J3.2 (DAT3/CD); also elsewhere on the board
SD_DET: J3.9 (DET_B); also elsewhere on the board

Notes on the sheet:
MAX-M10S: passive antenna on U.FL J4 (50 ohm trace, keep short). V_BCKP tied to 3V3 (no backup cell; hot start not retained).
VIO_SEL left open = default I/O level; verify against the u-blox MAX-M10S integration manual before production.
microSD holds the WDMAM anomaly tiles (~500 MB world), the WMM coefficients, the offline coastline map and the phone web UI.

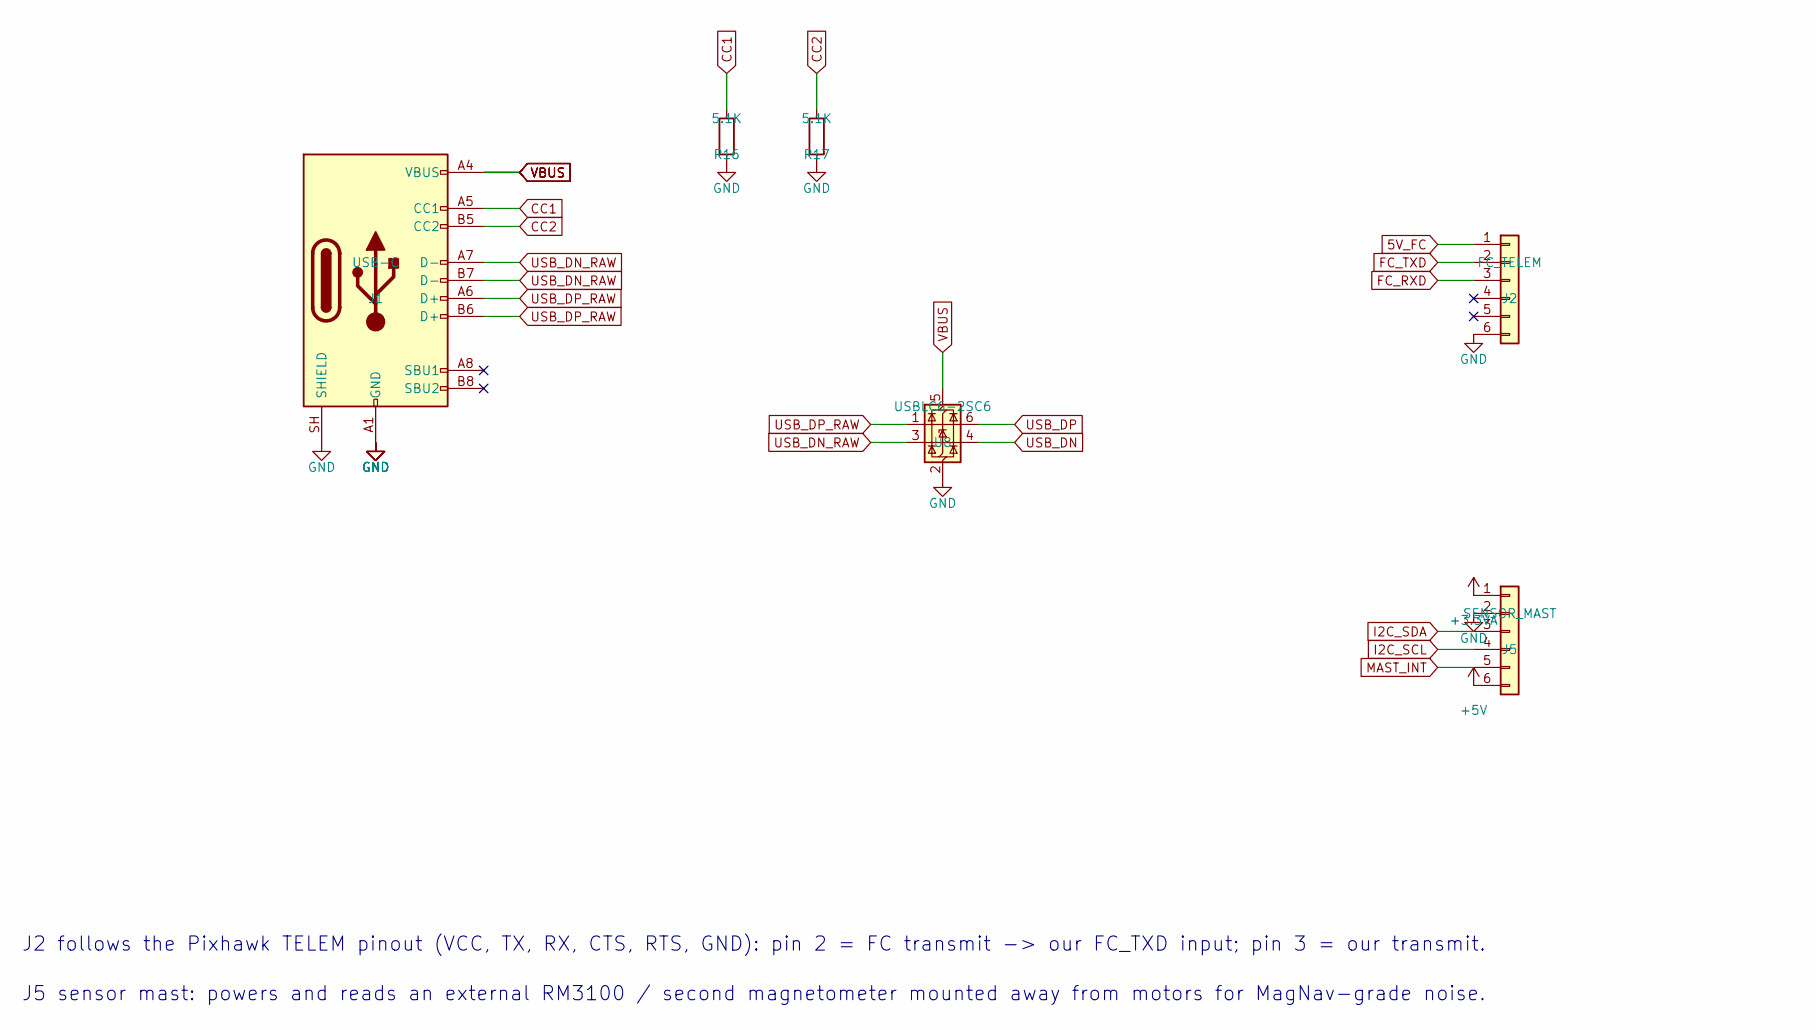
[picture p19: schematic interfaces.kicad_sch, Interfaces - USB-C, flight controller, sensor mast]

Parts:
J1: USB-C; USB_C_Receptacle_HRO_TYPE-C-31-M-12
J2: FC_TELEM; JST_GH_SM06B-GHS-TB_1x06-1MP_P1.25mm_Horizontal
J5: SENSOR_MAST; JST_GH_SM06B-GHS-TB_1x06-1MP_P1.25mm_Horizontal
R16, R17: 5.1K; R_0603_1608Metric
U8: USBLC6-2SC6; SOT-23-6

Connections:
+3.3VA: J5.1; also elsewhere on the board
CC1: J1.A5 (CC1), R16.1
CC2: J1.B5 (CC2), R17.1
FC_RXD: J2.3; also elsewhere on the board
FC_TXD: J2.2; also elsewhere on the board
I2C_SCL: J5.4; also elsewhere on the board
I2C_SDA: J5.3; also elsewhere on the board
MAST_INT: J5.5; also elsewhere on the board
USB_DN: U8.4 (I/O2); also elsewhere on the board
USB_DN_RAW: J1.A7 (D-), J1.B7 (D-), U8.3 (I/O2)
USB_DP: U8.6 (I/O1); also elsewhere on the board
USB_DP_RAW: J1.A6 (D+), J1.B6 (D+), U8.1 (I/O1)

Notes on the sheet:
J2 follows the Pixhawk TELEM pinout (VCC, TX, RX, CTS, RTS, GND): pin 2 = FC transmit -> our FC_TXD input; pin 3 = our transmit.
J5 sensor mast: powers and reads an external RM3100 / second magnetometer mounted away from motors for MagNav-grade noise.

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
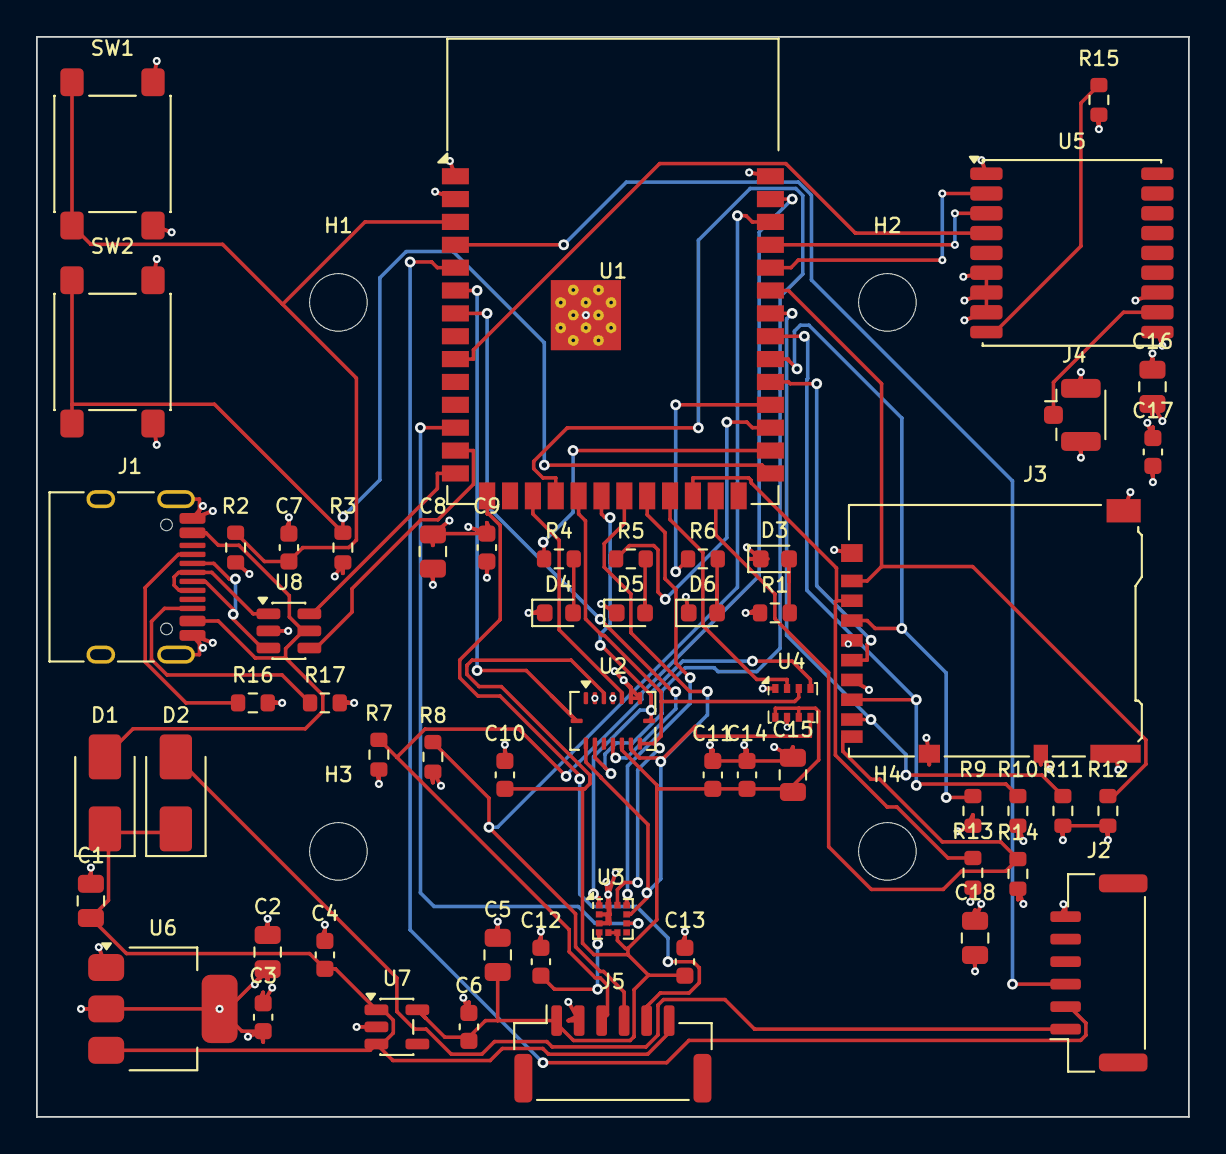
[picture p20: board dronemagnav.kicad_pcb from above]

Board: 4 copper layers, 64.0 x 60.0 mm, 60 parts (0 on the bottom side), 49 nets.

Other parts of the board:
H1, H2, H3, H4: M3; MountingHole_3.2mm_M3

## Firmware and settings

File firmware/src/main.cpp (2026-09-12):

// DroneMagNav firmware - ESP32-S3
//
// Sensor loop (100 Hz IMU, 80 Hz mag, 10 Hz baro) -> attitude (complementary
// filter) -> Tolles-Lawson compensated scalar field -> MagNav particle filter
// against WMM core field + WDMAM anomaly map from the SD card. GNSS initialises
// and (when present) benchmarks the filter; when GNSS is lost the MagNav
// estimate is fed to the flight controller as GPS_INPUT. Phone UI over WiFi.
#include <Arduino.h>
#include <SPI.h>
#include <SD_MMC.h>
#include "pins.h"
#include "sensors/bmi088.h"
#include "sensors/lis3mdl.h"
#include "sensors/bmp280.h"
#include "nav/geo.h"
#include "nav/wmm.h"
#include "nav/wdmam_map.h"
#include "nav/tolles_lawson.h"
#include "nav/particle_filter.h"
#include "comm/gnss.h"
#include "comm/mavlink_lite.h"
#include "comm/web_ui.h"

SPIClass spiBus(FSPI);
BMI088 imu(spiBus, PIN_CS_ACC, PIN_CS_GYR);
LIS3MDL mag(spiBus, PIN_CS_MAG);
BMP280 baro(spiBus, PIN_CS_BARO);
GNSS gnss(Serial1);
MavlinkLite mav(Serial2);
WMM wmm;
AnomalyMap worldMap, localMap;
TollesLawson tl;
MagNavPF pf;
WebUI web;

static bool sdOk = false, mapOk = false, wmmOk = false;
static bool magnavMode = false;         // true when GNSS lost / denied
static bool calibrating = false;
static float roll = 0, pitch = 0, yaw = 0;              // rad
static float bxf = 0, byf = 0, bzf = 0, bxPrev = 0, byPrev = 0, bzPrev = 0;
static float scalarComp = 0, anomAtEst = 0, altBaroM = 0, qnh = 101325;
static double estLat = 0, estLon = 0; static float estSigma = 9999, estBias = 0;
static uint32_t tLastImu = 0, tLastMag = 0, tLastBaro = 0, tLastPf = 0, tLastHb = 0,
                tLastGpsIn = 0;
static float vnDR = 0, veDR = 0;                        // dead-reckoning velocity

static float decimalYear() { return 2026.7f; }         // replace with RTC/GNSS date

// ---------------------------------------------------------------- attitude
static void attitudeUpdate(float ax, float ay, float az, float gx, float gy,
                           float gz, float dt) {
    roll += gx * dt; pitch += gy * dt; yaw += gz * dt;
    float an = sqrtf(ax * ax + ay * ay + az * az);
    if (an > 8.0f && an < 11.5f) {                    // near 1 g: trust accel
        float rollA = atan2f(ay, az), pitchA = atan2f(-ax, sqrtf(ay * ay + az * az));
        roll = 0.98f * roll + 0.02f * rollA;
        pitch = 0.98f * pitch + 0.02f * pitchA;
    }
    // tilt-compensated magnetic heading (WMM declination applied in caller)
    float mx = bxf * cosf(pitch) + bzf * sinf(pitch);
    float my = bxf * sinf(roll) * sinf(pitch) + byf * cosf(roll) - bzf * sinf(roll) * cosf(pitch);
    float yawMag = atan2f(-my, mx);
    yaw = 0.95f * yaw + 0.05f * yawMag;
}

// ---------------------------------------------------------------- callbacks
static void statusCb(NavStatus& s) {
    s.mode = calibrating ? "CAL" : (magnavMode ? "MAGNAV" : (gnss.fresh() ? "GNSS" : "INIT"));
    s.lat = estLat; s.lon = estLon; s.alt = altBaroM; s.sigmaM = estSigma;
    s.fieldNt = scalarComp; s.anomNt = anomAtEst; s.headingDeg = fmodf(yaw * 57.2958f + 360, 360);
    s.fcAlive = mav.fc().alive && (millis() - mav.fc().lastMs) < 3000;
    s.sdOk = sdOk; s.mapOk = mapOk; s.wmmOk = wmmOk;
    s.gnssFix = gnss.fresh(); s.sats = gnss.fix().sats; s.particles = MagNavPF::N;
}
static bool uploadCb(const double* lats, const double* lons, int n, float altRel) {
    static MavlinkLite::Waypoint wps[WebUI::MAXWP];
    for (int i = 0; i < n; i++) wps[i] = {lats[i], lons[i], altRel};
    mav.startMissionUpload(wps, n);
    uint32_t t0 = millis();
    while (millis() - t0 < 6000) {
        mav.poll();
        if (mav.uploadState() == MavlinkLite::Upload::Done) return true;
        if (mav.uploadState() == MavlinkLite::Upload::Failed) return false;
        delay(5);
    }
    return false;
}
static void calCb(bool start) {
    calibrating = start;
    if (start) tl.beginFit();
    else if (tl.solve()) { tl.save(SD_MMC); Serial.println("[cal] Tolles-Lawson saved"); }
}
static void initCb(double lat, double lon) {
    pf.init(lat, lon, 500.0f, 200.0f);
    estLat = lat; estLon = lon; magnavMode = true;
}
static float anomCb(double lat, double lon) {
    AnomalyMap& m = localMap.covers(lat, lon) ? localMap : worldMap;
    return m.lookup(lat, lon);
}

// ---------------------------------------------------------------- setup
void setup() {
    Serial.begin(115200);
    pinMode(PIN_LED_NAV, OUTPUT); pinMode(PIN_LED_FIX, OUTPUT); pinMode(PIN_LED_LINK, OUTPUT);
    pinMode(PIN_SD_DET, INPUT_PULLUP);
    // GNSS TIMEPULSE is tied inside the MAX-M10S to SAFEBOOT_N through 1 kOhm
    // (integration manual UBX-20053088, table 1): this pin must never be
    // driven low at receiver start-up or the module enters safeboot. Input only.
    pinMode(PIN_GNSS_PPS, INPUT);

    spiBus.begin(PIN_SPI_SCK, PIN_SPI_MISO, PIN_SPI_MOSI);
    Serial.printf("[imu] %s\n", imu.begin() ? "ok" : "FAIL");
    Serial.printf("[mag] %s\n", mag.begin() ? "ok" : "FAIL");
    Serial.printf("[baro] %s\n", baro.begin() ? "ok" : "FAIL");

    SD_MMC.setPins(PIN_SD_CLK, PIN_SD_CMD, PIN_SD_D0, PIN_SD_D1, PIN_SD_D2, PIN_SD_D3);
    sdOk = SD_MMC.begin("/sdcard", false);
    Serial.printf("[sd] %s\n", sdOk ? "ok" : "FAIL");
    if (sdOk) {
        wmmOk = wmm.load(SD_MMC, "/maps/WMM.COF");
        mapOk = worldMap.open(SD_MMC, "/maps/wdmam.bin");
        localMap.open(SD_MMC, "/maps/local.bin");
        tl.load(SD_MMC);
        Serial.printf("[wmm] %s  [map] %s  [tl] %s\n", wmmOk ? "ok" : "missing",
                      mapOk ? "ok" : "missing", tl.valid ? "ok" : "uncalibrated");
    }
    gnss.begin(PIN_GNSS_RX, PIN_GNSS_TX, 38400);
    mav.begin(PIN_FC_RX, PIN_FC_TX, 57600);
    web.begin(statusCb, uploadCb, calCb, initCb, anomCb);
    Serial.println("[web] AP DroneMagNav  http://192.168.4.1/");
}

// ---------------------------------------------------------------- loop
void loop() {
    uint32_t now = millis();
    gnss.poll(); mav.poll(); web.poll();

    if (now - tLastImu >= 10) {                       // 100 Hz
        float dt = (now - tLastImu) / 1000.0f; tLastImu = now;
        float ax, ay, az, gx, gy, gz;
        imu.readAccel(ax, ay, az); imu.readGyro(gx, gy, gz);
        attitudeUpdate(ax, ay, az, gx, gy, gz, dt);
        // crude IMU dead reckoning in the horizontal plane (used only when the
        // flight controller does not supply velocity)
        float aN = ax * cosf(yaw) - ay * sinf(yaw), aE = ax * sinf(yaw) + ay * cosf(yaw);
        vnDR = 0.995f * (vnDR + aN * dt); veDR = 0.995f * (veDR + aE * dt);
    }
    if (now - tLastMag >= 12) {                       // ~80 Hz
        float dt = (now - tLastMag) / 1000.0f; tLastMag = now;
        float bx, by, bz;
        mag.read(bx, by, bz);
        bxf = 0.8f * bxf + 0.2f * bx; byf = 0.8f * byf + 0.2f * by; bzf = 0.8f * bzf + 0.2f * bz;
        float bxd = (bxf - bxPrev) / dt, byd = (byf - byPrev) / dt, bzd = (bzf - bzPrev) / dt;
        bxPrev = bxf; byPrev = byf; bzPrev = bzf;
        float scalar = sqrtf(bxf * bxf + byf * byf + bzf * bzf);
        scalarComp = scalar - tl.correction(bxf, byf, bzf, bxd, byd, bzd);
        if (calibrating && gnss.fresh() && wmmOk) {
            float ref = (float)wmm.totalField(gnss.fix().lat, gnss.fix().lon,
                                              altBaroM / 1000.0, decimalYear()) +
                        (isnan(anomCb(gnss.fix().lat, gnss.fix().lon)) ? 0 : anomCb(gnss.fix().lat, gnss.fix().lon));
            tl.addSample(bxf, byf, bzf, bxd, byd, bzd, scalar - ref);
        }
    }
    if (now - tLastBaro >= 100) {                     // 10 Hz
        tLastBaro = now;
        float p, t; baro.read(p, t);
        altBaroM = BMP280::altitudeFromPressure(p, qnh);
    }

    // ---- navigation at 10 Hz ------------------------------------------
    if (now - tLastPf >= 100) {
        float dt = (now - tLastPf) / 1000.0f; tLastPf = now;
        bool fcVel = mav.fc().alive && (now - mav.fc().lastMs) < 1000;
        float vn = fcVel ? mav.fc().vn : vnDR, ve = fcVel ? mav.fc().ve : veDR;

        if (gnss.fresh() && !magnavMode) {
            estLat = gnss.fix().lat; estLon = gnss.fix().lon; estSigma = gnss.fix().hdop * 2.5f;
            if (!pf.initialised || estSigma < 20) pf.init(estLat, estLon, 50.0f, 100.0f);
        } else if (!gnss.fresh() && pf.initialised) {
            magnavMode = true;
        }
        if (magnavMode && pf.initialised && mapOk && wmmOk) {
            AnomalyMap& m = localMap.covers(estLat, estLon) ? localMap : worldMap;
            m.ensureWindow(estLat, estLon);
            pf.predict(vn, ve, dt, 1.5f, 5.0f);
            pf.update(scalarComp, wmm, m, altBaroM / 1000.0, decimalYear(), 40.0f);
            pf.estimate(estLat, estLon, estBias, estSigma);
            anomAtEst = m.lookup(estLat, estLon);
            if (now - tLastGpsIn >= 200) {
                tLastGpsIn = now;
                mav.sendGpsInput(estLat, estLon, altBaroM, estSigma, vn, ve, 3, 8);
            }
        } else if (mapOk) {
            AnomalyMap& m = localMap.covers(estLat, estLon) ? localMap : worldMap;
            m.ensureWindow(estLat, estLon);
            anomAtEst = m.lookup(estLat, estLon);
        }
        digitalWrite(PIN_LED_NAV, magnavMode && estSigma < 500);
        digitalWrite(PIN_LED_FIX, gnss.fresh());
        digitalWrite(PIN_LED_LINK, mav.fc().alive && (now - mav.fc().lastMs) < 3000);
    }
    if (now - tLastHb >= 1000) { tLastHb = now; mav.sendHeartbeat(); }
}

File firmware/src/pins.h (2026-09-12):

// DroneMagNav board pin map - matches schematic rev A (hardware/dronemagnav)
#pragma once

// SPI sensor bus (BMI088 accel/gyro, LIS3MDL magnetometer, BMP280 baro)
#define PIN_SPI_SCK    12
#define PIN_SPI_MOSI   11
#define PIN_SPI_MISO   13
#define PIN_CS_ACC     10
#define PIN_CS_GYR      9
#define PIN_CS_MAG     14
#define PIN_CS_BARO    21
#define PIN_INT_ACC     6
#define PIN_INT_GYR     7
#define PIN_MAG_DRDY    8

// GNSS (u-blox MAX-M10S) on the UART0 pads (GPIO43 TXD0 / GPIO44 RXD0);
// the console is the native USB-CDC port, so UART0 is free
#define PIN_GNSS_TX    43   // ESP TXD0 -> GNSS RXD
#define PIN_GNSS_RX    44   // GNSS TXD -> ESP RXD0
#define PIN_GNSS_PPS   16

// Flight controller MAVLink on UART2 (JST-GH TELEM pinout)
#define PIN_FC_TX       4   // ESP -> FC RX
#define PIN_FC_RX       5   // FC TX -> ESP

// I2C sensor-mast connector (external RM3100 etc.)
#define PIN_I2C_SDA     1
#define PIN_I2C_SCL     2
#define PIN_MAST_INT    3

// microSD, SDMMC 4-bit
#define PIN_SD_CLK     38
#define PIN_SD_CMD     39
#define PIN_SD_D0      40
#define PIN_SD_D1      41
#define PIN_SD_D2      42
#define PIN_SD_D3      47
#define PIN_SD_DET     48   // low = card present

// status LEDs
#define PIN_LED_NAV    35
#define PIN_LED_FIX    36
#define PIN_LED_LINK   37

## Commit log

2026-09-12 DroneMagNav rev A: magnetic-anomaly navigation board for drones
    ESP32-S3 + BMI088 + LIS3MDL + BMP280 + u-blox MAX-M10S + microSD.
    - KiCad schematics (5 sheets, ERC clean) and routed 4-layer 64x60 mm PCB
    (0 unconnected, 0 electrical DRC), fab outputs included
    - BOM with manufacturer part numbers
    - ESP32-S3 firmware: sensor drivers, WMM core field, WDMAM map window,
    Tolles-Lawson compensation, particle-filter MagNav, MAVLink GPS_INPUT +
    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
    [BOM.csv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]
2026-09-12 Fix WMM radial factor; validate evaluator against NOAA WMM2025 test values
    The (re/r) power series started one order low, making the field ~1% high
    at 77 km. tools/wmm_check.py ports the evaluator to Python and checks all
    100 official test points: worst error 0.001 nT. Docs updated.
    [make_design_doc.py, wmm_check.py]
2026-09-12 Build the WDMAM SD-card grid from the supplied v2 text file and verify it
    - prepare_sd.py: chunked pandas reader for the 1.5 GB / 26 M-line xyz
    distribution; roll the 180.00 column to the front so the grid starts at
    exactly -180 (matches the firmware longitude wrap)
    - wdmam_check.py: header/size check + 225 sample cells re-read from the
    source text, all identical (7200 x 3601 cells, 51.9 MB, 100 % valid)
    - docs + design PDF: record the file format and the verification result
2026-09-12 Remove leftover ATC RoIP branding from the schematic title blocks
    The sheet generator was copied from the other project and still stamped
    the ATC RoIP company name into the title block of the five sub-sheets, so
    it appeared on every schematic page and in Appendix A of the design
    document. The title block now reads DroneMagNav Project, and the netlist
    source path is project-relative. Schematic PDF and design document
    regenerated; ERC unchanged (0 errors, 1 expected BMI088 warning).
    [gnss_storage.kicad_sch, interfaces.kicad_sch, mcu.kicad_sch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]
2026-09-12 Move power vias out of pads, add fabrication notes, close the MAX-M10S strap question
    Auditing the routed board showed the power fanout had put 77 GND/+3V3 vias
    inside their own pads (not just the two BMI088 pads the docs mentioned):
    its candidate search started 0.25 mm from the pad centre and only checked
    other-net copper.
    - tools/dogbone_vias.py: two-pass (remove / add) re-fanout. 74 vias now sit
    outside their pads on short stubs; pads matched by position (SW/J3/J4 have
    duplicate pad numbers), keep-outs tested with the real polygons, stubs
    checked too, board-edge margin honoured. Three vias have provably no room
    (BMI088 pads 2/4 between 0.5 mm-pitch escapes over the body keep-out,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
    [dronemagnav-B_Courtyard.gbr, dronemagnav-B_Cu.gbl, dronemagnav-B_Fab.gbr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]
2026-09-12 Compile-verify the firmware and ship flashable images
    - platformio.ini: build with the pioarduino espressif32 platform (Arduino-ESP32
    core 3.3.11, packages served from GitHub releases; the PlatformIO registry
    mirror stalled three times at a few hundred kB/s).
    - First build: SUCCESS, 0 warnings, flash 1,077,723 B (25.7 % of the 4 MB app
    partition), RAM 95,876 B (29.3 %).
    - firmware/release/: dronemagnav-firmware.factory.bin (bootloader + partition
    table + app, flash at 0x0), plus the separate bootloader, partitions and app
    images; esptool one-liner in firmware/README.md.
    - README, design spec and design PDF record the build result.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
    [make_design_doc.py]
2026-09-12 Add JLCPCB-format placement list (CPL) and BOM
    tools/make_jlc.py converts the KiCad pick-and-place export and docs/BOM.csv
    into JLCPCB's upload columns (Designator/Mid X/Mid Y/Layer/Rotation and
    Comment/Designator/Footprint/LCSC Part #/Manufacturer/MPN). The LCSC column is
    left blank on purpose so the uploader matches on MPN and each match is
    confirmed by a person. The script cross-checks that every placed part is in
    the BOM and vice versa.
    [dronemagnav-B_Courtyard.gbr, dronemagnav-B_Cu.gbl, dronemagnav-B_Fab.gbr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]
2026-09-13 JLCPCB BOM: descriptive comments and LCSC numbers confirmed by JLCPCB's matcher
    docs/lcsc-parts.csv records the part numbers JLCPCB's BOM tool itself matched or proposed for the DroneMagNav BOM, plus which rows still need a manual pick (LEDs, switches, connectors). make_jlc.py n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
    [dronemagnav-B_Courtyard.gbr, dronemagnav-B_Cu.gbl, dronemagnav-B_Fab.gbr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]
2026-09-13 LCSC map: key generic capacitor MPNs by value, fix MAX-M10S key
    [dronemagnav-B_Courtyard.gbr, dronemagnav-B_Cu.gbl, dronemagnav-B_Fab.gbr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]
2026-09-13 JLCPCB BOM: explicit Quantity column, value-style comments
    [dronemagnav-B_Courtyard.gbr, dronemagnav-B_Cu.gbl, dronemagnav-B_Fab.gbr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]
2026-09-13 PCBWay assembly files: centroid (Altium layout, bottom-left origin, pad-1) and BOM template csv/xlsx
    [dronemagnav-B_Courtyard.gbr, dronemagnav-B_Cu.gbl, dronemagnav-B_Fab.gbr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]
2026-09-13 Assembly instruction package for the assembler: orientation/polarity table, handling rules, ESP32 programming steps, functional test procedure, KiCad top assembly drawing; zipped with the firmware im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
2026-09-13 Ignore the assembly-doc intermediate PDF
2026-09-13 Assembly drawing: filled title block, U1 reference texts moved onto the board, 1.5:1 plot without values; fab package regenerated
    [dronemagnav-B_Courtyard.gbr, dronemagnav-B_Cu.gbl, dronemagnav-B_Fab.gbr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]
